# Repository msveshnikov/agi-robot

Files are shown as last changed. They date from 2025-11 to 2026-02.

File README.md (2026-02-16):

# AGI Robot

This project creates a **fully autonomous, LLM-powered mobile robot** that uses **Google Gemini 3 Flash** for real-time decision-making, navigation, and human interaction. The robot combines computer vision, distance sensing, and multi-modal AI to explore environments, accomplish goals, and engage in natural conversations.

[robot.mvpgen.com](https://robot.mvpgen.com)

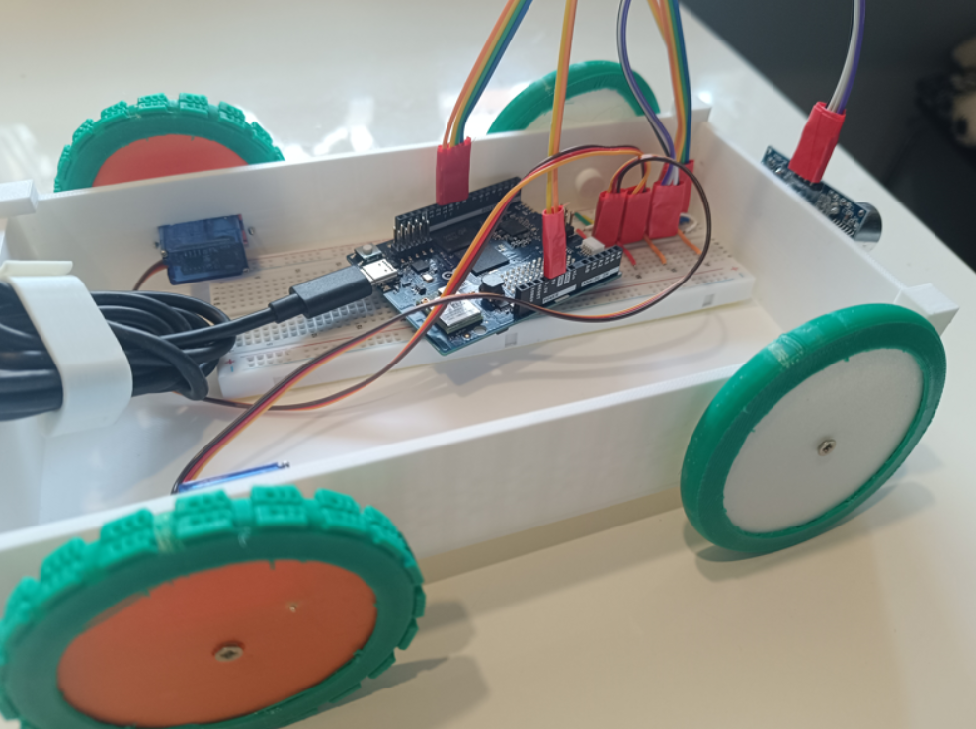
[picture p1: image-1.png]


## Key Features

- 🤖 **Autonomous Navigation**: LLM-driven pathfinding with obstacle avoidance and spatial mapping
- 👁️ **Computer Vision**: Real-time image analysis for object detection and scene understanding
- 🎤 **Voice Interaction**: Dynamically records user responses (3-15s) based on noise levels, sends audio to LLM for context-aware replies
- 🗣️ **Multi-language TTS**: Supports English, Russian, Czech, Italian, and German with Google Chirp3/Chirp-HD voices
- 🌈 **Emotional Expression**: RGB LED "mood" changes based on robot's state and manual RGB selector in dashboard
- 🏗️ **Manipulator Arm**: 2-DOF robotic arm for physical interaction with the environment (base + joint control)
- 📊 **Web Dashboard**: Modern glassmorphism interface (React/Vite) for remote monitoring, real-time telemetry, and manual override
- 📽️ **Live Camera Feed**: Real-time video streaming from robot to dashboard via Socket.IO
- 📓 **Robot Diary**: Daily "Sartre-style" blog posts automatically generated from cognitive logs
- 🧠 **Memory & Planning**: Maintains movement history, spatial maps, and hierarchical plans with file-based persistence
- � **Sound Effects**: Plays contextual sounds to attract attention or express personality
- 🚨 **Safety Features**: Panic mode for emergency navigation and Telegram alarm notifications
- 📸 **Data Logging**: Automatic image capture to Google Drive for training datasets

## Current Specifications

-   **Core Hardware:** Arduino Uno Q (Microcontroller/Motor Control)
-   **Physical Dimensions:** 24cm wide, 12cm long, **10cm high**
-   **Movement:** Two wheels with 360-degree movement capability (differential drive) - **Pins 11 (Left) & 10 (Right)**. Note: Robot can move **ONLY on the floor**.
-   **Peripherals:** USB-C dongle (USB Camera with Mic, Bluetooth Speaker)
-   **Sensors:**
    -   Proximity/Distance Sensor (Trig Pin 8, Echo Pin 9)
    -   **Modulino Thermo** (Temperature & Humidity) - Connected via I2C/Qwiic
    -   RGB LED for mood expression
-   **Power:** PowerBank 10000 mAh
-   **Software Stack:** Python 3.12+, Node.js 20+, React 18, MongoDB, Google Cloud Vertex AI (Gemini 3 Flash / Gemini 3 Pro), Pydantic (Structured Outputs)
-   **Connectivity:** WiFi required for API and Dashboard access

**Functionality:** The robot operates autonomously using an AGI loop: captures images, measures distance, consults the LLM, speaks responses, records user audio, and executes movement commands. All decisions are made by the AI model based on visual input, sensor data, goals, and conversation context.

## Project Cost

Below is a table listing all main components, their approximate cost (in USD, based on AliExpress prices), and the total amount.

| Component | Description | Cost (USD) |
| :--- | :--- | ---: |
| **Arduino Uno Q** | Main microcontroller of the project | $44 |
| **2 x SG90 9g Servos** | Motors for wheels (360°) | $4 |
| **2 x SG90 9g Servos** | Motors for manipulator arm (180°) | $4 |
| **Webcam** | Cheap Chinese USB webcam (for visual input) | $3 |
| **USB Dongle (Adapter)** | For connecting webcam and PD | $3 |
| **Ultrasonic Sensor** | For distance measurement (e.g., HC-SR04) | $1.5 |
| **Bluetooth Speaker** | For audio output or feedback | $2.5 |
| **Solderless Breadboard and Wires** | For prototyping and component connections | $5 |
| **3D Printing Plastic** | About 200 grams (for case, mounts, etc., at ~$15/kg) | $3 |
| **Xiaomi Powerbank** | 10000 mAh (for power) | $10 |
| **3D Printer** | Gift, not counted | $0 |
| **Total Project Cost** | | **$80** |

As shown in the table, the total project cost is a very affordable **$80 USD**. This clearly demonstrates that implementing interesting and functional DIY solutions doesn't always require significant investments.

**Arduino Board:** The main portion of the budget goes to the controller. Choosing more budget-friendly boards (e.g., ESP32 or ESP8266, if functionality allows) could further reduce this expense.

**Peripherals:** The webcam, dongle, sensor, and speaker are typical representatives of inexpensive yet fully functional modules widely available on the market.

**Consumables:** The cost of 3D printing plastic and basic prototyping elements (breadboard, wires) is also minimal.

### LLM API Running Cost

The robot's consciousness operates in an autonomous loop, which incurs API costs for the LLM (Gemini):
- **Loop Duration**: ~20 seconds per consciousness loop
- **Cost per Loop**: $0.005
- **Cost per Hour**: ~$1.0 (continuous operation)

---

## Design Ideas and Future Considerations

### 1. Hardware Enhancements and Modularity

| Area | Current Status | Proposed Enhancement | Rationale |
| :--- | :--- | :--- | :--- |
| **Microcontroller** | Arduino Uno Q | | |
| **Motor Control** | Integrated with Uno Q | Dedicated Motor Driver Shield (e.g., L298N or specialized drivers) | Better current handling, precision control, and separation of logic/power circuits. |
| **Sensing/Navigation** | USB Camera + Proximity + Modulino Thermo | Integrate IMU (Accelerometer/Gyroscope) | Enable robust spatial awareness, obstacle avoidance, and precise movement/pose tracking. |
| **Physical Structure** | Custom 3D Printed Chassis | | Modular housing for components, better stability, and improved aesthetics for component housing. |
| **Power Management** | Single PowerBank | | Ensure stable power for SBC, motors, and peripherals; implement low-power warning system. |

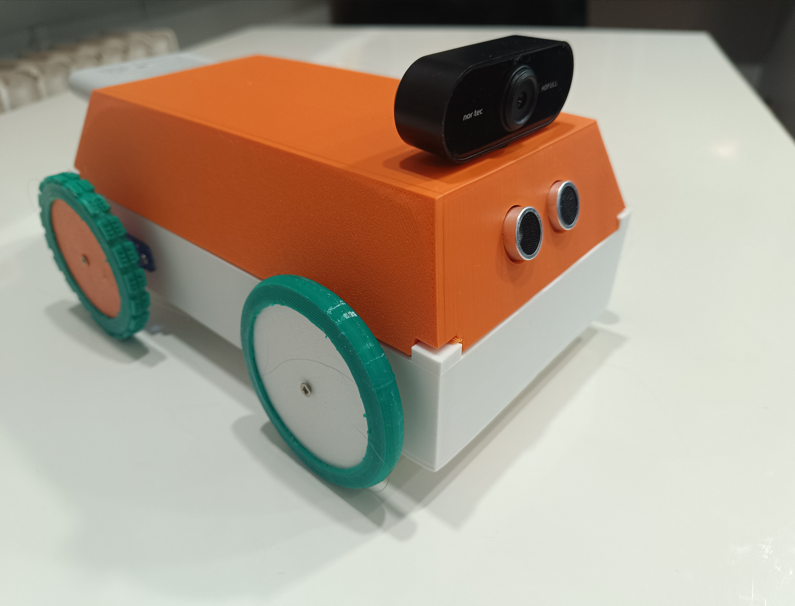
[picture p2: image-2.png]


### 2. Software Architecture and Code Structure

-   **Python Logic (`main.py`):**
    -   **AGI Loop**: Implements an autonomous loop (`agi_loop`) where the robot captures an image, checks distance, records audio responses, and consults the Gemini 3 Flash model via `media_service.py` to decide on actions.
    -   **Audio Recording**: After the robot speaks, it records user audio with **dynamic duration** (3 to 15 seconds). It monitors noise levels (dB) to extend recording if the user is speaking, and stops early on silence. During recording, the RGB LED displays a **rainbow effect**.
    -   **Object Detection**: Uses `VideoObjectDetection` to identify objects in real-time and announce them (`send_detections_to_ui`).
    -   **Backend API / Custom Backend**: Synchronizes state variables (`speed`, `agi`, `goal`, `lang`, `rgb`) and telemetry (`distance`, `temperature`, `humidity`) with our Node.js backend and web dashboard.
    -   **RGB Mood**: Converts HSV color values from backend state to RGB for the robot's "mood" LED.
    -   **Movement History**: Tracks all movement commands to prevent loops and aid navigation.
    
-   **Media Service (`media_service.py`):**
    -   **HTTP Server** (Port 5000) with the following endpoints:
        -   **GET `/play`**: Plays audio files via `aplay` (parameter: `filename`)
        -   **GET `/play_random`**: Plays a random sound from the `sounds` directory
        -   **GET `/speak`**: Text-to-Speech using Google Cloud TTS (parameters: `text`, `lang`)
            - Supports multiple languages:
              - English: `en-US-Chirp3-HD-Zubenelgenubi`
              - Russian: `ru-RU-Wavenet-D`
              - Czech: `cs-CZ-Chirp3-HD-Enceladus`
              - Italian: `it-IT-Chirp-HD-D`
              - German: `de-DE-Chirp-HD-D`
            - Implements caching to avoid re-synthesizing the same text
            - Audio output: LINEAR16 with +10dB volume gain for clarity
        -   **GET `/telegram`**: Sends alarm messages to admin via Telegram Bot (parameter: `message`)
            - Requires `TELEGRAM_KEY` and `ADMIN_ID` environment variables
        -   **POST `/llm_vision`**: Sends image, distance, plan, subplan, map, movement history, **and audio** to Gemini LLM
            - Parameters: `asi` (bool) - to select model:
                - `false` (default): **Gemini 3 Flash ** (Fast, low latency)
                - `true`: **Gemini 3 Pro** (High reasoning, slower)
            - Returns JSON with: `speak`, `sound`, `move`, `rgb`, `plan`, `subplan`, `map`, `memory`, `alarm`
            - Receives images via Socket.IO from the webcam service (default: `http://localhost:4912`)
            - **Image Logging**: Saves all incoming images to `/home/arduino/google-drive/robot` with timestamps for debugging/dataset creation
            - Includes sophisticated prompt engineering for robot behavior and safety rules
            - **Reasoning**: Uses a thinking budget (16k tokens) for complex chain-of-thought processing
            - **Alarm System**: Automatically sends Telegram notifications when LLM detects critical/dangerous conditions

-   **Arduino MCU (`sketch.ino`):**
    -   **Libraries Used**: `Arduino_RouterBridge`, `Modulino`, `Servo`, `NewPing`
    -   **Main Loop Operations**:
        1. Reads ultrasonic distance sensor (NewPing library) every 1 second
        2. Reads temperature and humidity from Modulino Thermo (I2C)
        3. Updates Cloud telemetry via Bridge notifications (`set_distance`, `set_temperature`, `set_humidity`)
    -   **Python Control Loop** (`main.py`):
        - Executes movement commands based on cloud variables (`speed`, `back`, `left`, `right`, `forward`, `panic`, `agi`)
        - Priority order: Manual controls → Panic mode → AGI mode → Stop
    -   **Manual Control**: Individual direction booleans (`back`, `left`, `right`, `forward`) with configurable speed
    -   **Panic Mode**: Emergency navigation mode - moves forward if clear (>25cm), otherwise backs up, plays random sound, and rotates
    -   **AGI Mode**: Calls `agi_loop()` function in Python, receives LLM decisions, executes complex multi-step commands
    -   **RGB Parsing**: Converts "R,G,B" string to individual values, applies hardware color correction (Red÷1.2, Green÷2, Blue×1)
    -   **Movement Calibration**:
        - Linear: ~20 cm/sec at speed 45
        - Rotation: ~40 ms/degree (empirical)
        - Safety: Stops forward movement if distance < 10cm
    -   **Bridge Functions Exposed**: `getDistance()`, `setRGB(string)`, `move(string, bool)`, `panic(int)`

# Robot Hardware Schema

## Overview

The Uno Q consists of an MCU handling motor control and an MPU (Linux Environment) handling high-level logic, vision, and audio.

## Connection Diagram

```mermaid
graph TD
    subgraph Web ["Web Infrastructure (Custom Cloud)"]
        Dashboard["React Dashboard (robot.mvpgen.com)"]
        Backend["Node.js Backend & Socket.IO"]
        DB["MongoDB (State & Logs)"]
        
        Dashboard <--> Backend
        Backend <--> DB
    end

    subgraph MPU ["MPU (Linux/Python)"]
        Python["Python Script (main.py)"]
        MediaService["Media Service (media_service.py)"]
        Webcam["USB Webcam"]
        Mic["USB Microphone"]
        Speaker["Bluetooth Speaker"]

        Python <--> MediaService
        MediaService <--> Webcam
        MediaService <--> Mic
        MediaService <--> Speaker
        MediaService <--> VertexAI["Google Vertex AI (Gemini)"]
    end

    subgraph MCU ["MCU (Arduino)"]
        Bridge["Arduino_RouterBridge"]
        ServoL["Servo Left (Pin 11)"]
        ServoR["Servo Right (Pin 10)"]
        Sensor["Proximity Sensor (Trig 8, Echo 9)"]
        Modulino["Modulino Thermo (I2C)"]
        RGB["RGB LED"]

        Bridge --> ServoL
        Bridge --> ServoR
        Bridge --> Sensor
        Bridge --> Modulino
        Bridge --> Matrix["LED Matrix (Built-in)"]
        Bridge --> RGB
    end

    Python <-->|Internal Serial| Bridge
    Python <-->|HTTP / REST| Backend
```

## Pinout Configuration

| Component | Arduino Pin | Description |
| :--- | :--- | :--- |
| **Servo Left**  | D11 | Left Wheel (Continuous Rotation)  |
| **Servo Right** | D10 | Right Wheel (Continuous Rotation) |
| **Sensor** | D8, D9 | Proximity/Distance (Trig/Echo) |
| **Modulino** | I2C | Temperature & Humidity Sensor |
| **Matrix** | Built-in | 12x8 LED Matrix |
| **RGB LED** | D4, D6, D2  | Red, Green, Blue (Common Cathode) |
| **Arm Servo 1** | D3 | Manipulator Arm Base (0-180°) |
| **Arm Servo 2** | D5 | Manipulator Arm Joint (0-180°) |
| **USB** | USB Port | Serial Communication/Webcam |

## Backend State Variables

The following variables are synchronized with the project's backend API and web dashboard (replacing Backend):

-   **Read/Write (Controls):**

    -   `agi` (bool): Master switch to enable/disable the autonomous AGI loop.
    -   `asi` (bool): Toggle to use **Gemini 3 Pro** (Smarter) instead of Flash (Faster).
    -   `goal` (str): Current main goal for the robot (retrieved from cloud).
    -   `speed` (int): Controls the speed of the robot (0-90, where 45 is baseline).
    -   `back` (bool): Command to move backward.
    -   `left` (bool): Command to turn left.
    -   `right` (bool): Command to turn right.
    -   `forward` (bool): Command to move forward.
    -   `rgb` (CloudColoredLight): RGB LED control with HSV values:
        -   `rgb:hue` (0-360): Hue value
        -   `rgb:sat` (0-100): Saturation percentage
        -   `rgb:bri` (0-100): Brightness percentage
        -   `rgb:swi` (bool): Switch on/off
        -   The Python code converts HSV to RGB string format (e.g., "255,128,0") and sends to MCU
    -   `lang` (str): Language code for TTS (en, ru, cz/cs, it, de) or "disabled" for silent mode.
    -   `panic` (bool): Emergency navigation mode toggle.
    -   `arm1` (int): Control angle for Arm Servo 1 (0-180).
    -   `arm2` (int): Control angle for Arm Servo 2 (0-180).

-   **Read-Only (Telemetry):**
    -   `distance` (int): Distance measured by the ultrasonic sensor (cm).
    -   `temperature` (float): Temperature from Modulino sensor (Celsius).
    -   `humidity` (float): Humidity from Modulino sensor (%).
    -   `plan` (str): Current global strategy/reasoning from LLM.
    -   `subplan` (str): Current tactical action description.
    -   `space_map` (str): Text-based 2D spatial map.
    -   `movement_history` (str): JSON array of past movement commands.
    -   `memory` (str): Persistent facts/knowledge learned by the robot.
    -   `alarm` (str): Current alarm status/message (empty = no alarm).

## Power Distribution

-   **Arduino**: Powered via USB PowerBank

## MPU Requirements

-   **OS**: Linux Debian 13
-   **Python**: 3.12+
-   **Ports**: 1x USB-C host for Arduino, 1x USB-A for Webcam with mic.
-   **Dependencies**: 
    -   `arduino-app-utils` (Arduino Bridge)
    -   `google-genai` (Gemini API)
    -   `google-api-python-client` (Google TTS)
    -   `python-socketio[client]` (Image streaming)
    -   `aplay` (Audio playback utility)

## Setting Up Autostart on Debian

To automatically start `media_service.py` on boot in Debian, the repository includes systemd service configuration files in the `etc/` folder.

### Installation Steps

1. **Copy the rc.local script** to `/etc/`:
   ```bash
   sudo cp etc/rc.local /etc/rc.local
   sudo chmod +x /etc/rc.local
   ```

2. **Edit `/etc/rc.local`** to update paths and credentials:
   ```bash
   sudo nano /etc/rc.local
   ```
   
   Update the following variables:
   - `GEMINI_KEY`: Your Google Gemini API key
   - Bluetooth MAC address (if using different speaker)
   - Paths to match your installation directory

3. **Copy the systemd service** file:
   ```bash
   sudo cp etc/rc-local.service /etc/systemd/system/rc-local.service
   ```

4. **Enable and start the service**:
   ```bash
   sudo systemctl daemon-reload
   sudo systemctl enable rc-local.service
   sudo systemctl start rc-local.service
   ```

5. **Check service status**:
   ```bash
   sudo systemctl status rc-local.service
   ```

### What the Script Does

The `rc.local` script performs the following on boot:
- Waits 20 seconds for system initialization
- Sets the `GEMINI_KEY` environment variable
- Connects to the Bluetooth speaker (via `bluetoothctl`)
- Creates required runtime directories for PulseAudio (`/run/user/1000/pulse`)
- Plays a startup sound to confirm audio is working
- Starts `media_service.py` from the Python directory

### Troubleshooting

- **Check logs**: `journalctl -u rc-local.service -f`
- **Manual test**: Run `/etc/rc.local start` as the arduino user
- **Bluetooth issues**: Verify speaker MAC address with `bluetoothctl devices`
- **Audio issues**: Test with `aplay -l` to confirm sound card detection

---

## Configuration

### Environment Variables

The system requires the following environment variables:

-   **`GOOGLE_APPLICATION_CREDENTIALS`**: Path to Google Cloud service account JSON file
    - Linux: `/home/arduino/google.json`
    - Windows: `C:\My-progs\Python\agi-robot\google.json`
-   **`GEMINI_KEY`**: Google Gemini API key for LLM access
-   **`IMAGE_SERVER_URL`**: Socket.IO server URL for webcam feed (default: `http://localhost:4912`)
-   **`TELEGRAM_KEY`** (optional): Telegram Bot API token for alarm notifications
-   **`ADMIN_ID`** (optional): Telegram chat ID for receiving robot alarms

### File Structure

```
agi-robot/
├── python/
│   ├── main.py              # Main robot control logic
│   ├── media_service.py     # HTTP server for TTS, LLM, and audio
│   ├── sounds/              # Directory for random sound effects (.wav files)
│   ├── memory.txt           # Persistent memory storage (auto-created)
│   └── mic.wav              # Temporary audio recording (auto-deleted after use)
├── sketch/
│   └── sketch.ino           # Arduino MCU firmware
└── google.json              # Google Cloud credentials
```

### Startup Behavior

On initialization, the robot:
1. Connects to the backend API/site and synchronizes variables
2. Initializes the webcam object detection stream
3. **RGB Rainbow**: Performs a color cycle sequence on the LED to indicate hardware readiness
4. Plays a startup sound
5. Speaks "Robot is ready" in the configured language
6. Sets default goal: **"Be helpful assistant to the master human"**
7. Begins listening for backend variable changes (AGI mode, manual controls, goal updates)

### Default Main Goal

The robot's default goal is **"Be helpful assistant to the master human"**, but this can be changed via the backend `goal` variable. When a new goal is set from the backend, the robot will speak the new goal and update its behavior accordingly.

---

## AGI Loop Behavior

The AGI Loop is the core autonomous decision-making cycle of the robot. It operates as follows:

### Input Processing

1. **Visual Input**: Captures live image from webcam via Socket.IO connection
2. **Distance Sensing**: Reads ultrasonic sensor data (0-1000 cm)
3. **Context State**: Maintains `plan`, `subplan`, `space_map`, and `movement_history`
4. **Audio Input**: After speaking, dynamically records (3-15s) to capture user responses
5. **Main Goal**: Retrieved from the backend `goal` variable

### LLM Decision-Making

The robot sends all inputs to **Gemini LLM** (Flash or Pro based on `asi` setting) with a sophisticated prompt that includes:

-   **Safety Rules**: Must stop or turn if distance < 25cm to avoid collisions (Hardware failsafe stops motors at <10cm)
-   **Navigation Strategy**: Systematic scanning by turning 30-60 degrees, approaching targets
-   **Social Behavior**: Use casual sounds to attract human attention
-   **Memory Management**: Use history to avoid loops and repeated actions
-   **Planning Hierarchy**: Global `plan` for overall strategy, `subplan` for immediate steps
-   **Spatial Mapping**: Maintain and update a text-based 2D map (1x1 meter blocks)
-   **Mood Expression**: RGB LED color reflects robot's emotional state

### LLM Response Format

The model returns a structured JSON object validated by Pydantic schemas:

```json
{
  "speak": {"text": "What I want to say"},
  "sound": "casual",
  "moves": [
    {"command": "forward|back|left|right|stop", "distance_cm": 20-300, "angle_deg": 10-180}
  ],
  "rgb": "R,G,B",
  "arm1": 0-180,
  "arm2": 0-180,
  "plan": "Global strategy description",
  "subplan": "Immediate next steps",
  "space_map": "Text-based spatial map with legend",
  "memory": "Updated persistent knowledge",
  "alarm": "Critical condition description (or empty string)"
}
```

### Action Execution

1. **Speech**: Uses Google TTS with language-specific Chirp/WaveNet voices (en/ru/cz/it/de)
2. **Audio Recording**: Captures 3-15 seconds of audio (dynamic extension) while cycling RGB colors (Rainbow) to indicate listening state.
3. **Sound Effects**: Plays random sound from `sounds/` directory to attract attention
4. **RGB Mood**: Updates LED color based on robot's emotional state:
   - White (255,255,255): Neutral/Ready
   - Green (0,255,0): Happy/Success
   - Red (255,0,0): Blocked/Frustrated
   - Blue (0,0,255): Thinking/Processing
   - Yellow (255,255,0): Curious/Searching
   - Orange (255,165,0): Cautious/Obstacle Nearby
   - Purple (128,0,128): Excited/Special Discovery
5. **Movement**: Sends command string to MCU via Bridge notification
6. **Memory**: Saves updated memory to `memory.txt` for persistence across sessions
7. **Alarm**: If alarm is non-empty, sends Telegram notification to admin
8. **Backend Sync**: Updates all state variables to the backend API and web dashboard for remote monitoring

## MCU Command Protocol

The MCU executes movement commands received from the AGI loop via the `agi_loop()` bridge function.

### Command Format

Commands are formatted as pipe-delimited strings:

**MOVE Command:**
```
MOVE|direction|distance_cm|speed
```
- `direction`: `forward` or `back`
- `distance_cm`: Distance to travel (integer)
- `speed`: Motor speed 0-90 (45 is baseline)

**TURN Command:**
```
TURN|direction|angle_deg|speed
```
- `direction`: `left` or `right`
- `angle_deg`: Rotation angle (integer)
- `speed`: Motor speed 0-90

**STOP Command:**
```
STOP
```

### Movement Calibration

The MCU uses empirical calibration values:
- **Linear Movement**: ~20 cm/sec at speed 45
- **Rotation**: ~30 ms/degree at speed 45
- Speed scaling: `actual_speed = base_speed * (requested_speed / 45.0)`

### RGB LED Processing

The MCU receives RGB values as a comma-separated string (e.g., "255,128,0") and applies color correction:
- Red: `value / 1.2`
- Green: `value / 2`
- Blue: `value` (no correction)

---

### Completed Features ✓
- [x] Multi-language TTS (English, Russian, Czech, Italian, German)
- [x] Audio recording after speech for user responses
- [x] Movement history tracking
- [x] Spatial mapping hints to LLM
- [x] RGB mood expression based on robot state
- [x] Proximity sensor integration
- [x] Google grounding for real-time web search
- [x] Persistent conversation memory across sessions (file-based)
- [x] Panic mode for emergency navigation
- [x] Telegram alarm notifications
- [x] Image logging to Google Drive
- [x] Temperature and humidity monitoring
- [x] Structured Outputs (Pydantic) for type-safe LLM responses
- [x] Manipulator arm with 2 SG90 180° servos on the roof for object interaction 
- [x] Migrate to custom backend & dashboard (React + Node.js + MongoDB)
- [x] Real-time camera feed integration in the dashboard
- [x] Settings panel in dashboard
- [x] Daily blog post (Robot Diary) from the cognitive logs
- [x] Native webcam, no bricks anymore
- [x] Broadcast robot speaking to all web clients

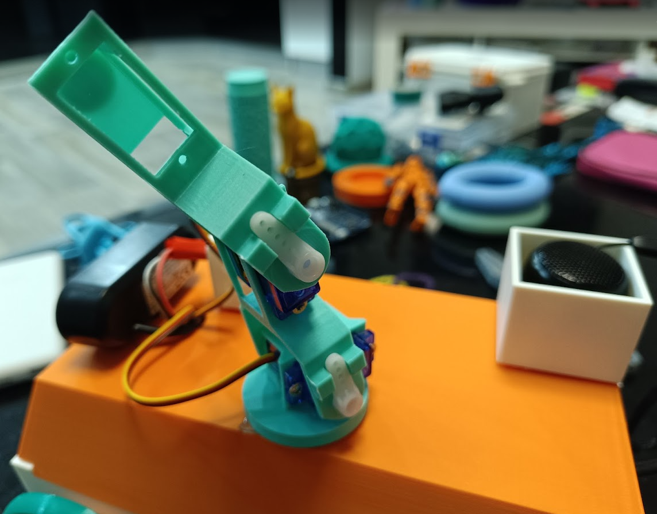
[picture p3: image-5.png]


# TODO

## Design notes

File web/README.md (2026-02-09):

# AGI Robot Web Application

Complete web interface for the AGI Robot project with React frontend, Node.js backend, and MongoDB database.

## Project Structure

```
web/
├── frontend files (React + Vite)
│   ├── src/
│   │   ├── pages/
│   │   │   ├── LandingPage.jsx
│   │   │   └── LandingPage.css
│   │   ├── App.jsx
│   │   ├── main.jsx
│   │   └── index.css
│   ├── public/
│   │   └── (robot images)
│   ├── index.html
│   ├── package.json
│   ├── Dockerfile                  # Frontend multi-stage build
│   └── nginx.conf                  # Nginx config for frontend
├── backend/
│   ├── models/
│   │   ├── RobotState.js           # Robot state schema
│   │   ├── TelemetryLog.js         # Telemetry logging
│   │   └── CommandLog.js           # Command audit trail
│   ├── routes/
│   │   └── api.js                  # REST API endpoints
│   ├── server.js                   # Express server + Socket.IO
│   ├── package.json
│   ├── Dockerfile                  # Backend Node.js image
│   ├── .env.example
│   ├── .env                        # Local development
│   ├── .env.production             # Docker production
│   └── README.md
├── docker-compose.yml              # Multi-container orchestration
└── DEPLOYMENT.md                   # Deployment guide
```

## Features

### Frontend
- 🎨 Stunning landing page with glassmorphism design
- ⚡ React 18 with Vite for fast development
- 🎭 Framer Motion animations
- 📱 Responsive design (mobile, tablet, desktop)
- 🎯 Lucide React icons

### Backend
- 🚀 Express.js REST API
- 📊 MongoDB with Mongoose ODM
- 🔄 Socket.IO for real-time updates
- 📝 Command and telemetry logging
- 🏥 Health checks

### Deployment
- 🐳 Docker Compose orchestration
- 📦 Multi-stage builds for optimization
- 🔄 GitHub Actions CI/CD
- 🌐 Automated deployment to robot.mvpgen.com

## Quick Start

### Local Development

**Prerequisites**: Node.js 18+, MongoDB (or use Docker Compose)

```bash
# Clone repository
git clone https://github.com/msveshnikov/agi-robot.git
cd agi-robot/web

# Start with Docker Compose (recommended)
docker-compose up -d

# OR run manually:

# Terminal 1 - Backend
cd backend
npm install
cp .env.example .env
npm run dev

# Terminal 2 - Frontend
cd ..
npm install
npm run dev
```

Visit:
- Frontend: http://localhost:5173
- Backend API: http://localhost:3000/api/health

### Production Deployment

See [DEPLOYMENT.md](DEPLOYMENT.md) for complete Docker Compose deployment guide.

```bash
# On VPS
cd /var/www/agi-robot
docker-compose up -d
```

## Technology Stack

**Frontend**
- React 18
- Vite
- React Router DOM
- Framer Motion
- Lucide React
- Axios
- Socket.IO Client

**Backend**
- Node.js 20
- Express.js
- MongoDB + Mongoose
- Socket.IO
- CORS
- Morgan (logging)

**DevOps**
- Docker & Docker Compose
- GitHub Actions
- Nginx (frontend server)

## Environment Variables

### Backend (.env)

```env
MONGODB_URI=mongodb://localhost:27017/agi-robot
PORT=3000
NODE_ENV=development
CORS_ORIGIN=http://localhost:5173
PYTHON_MEDIA_SERVICE_URL=http://localhost:5000
```

### Docker Production (.env.production)

```env
MONGODB_URI=mongodb://mongodb:27017/agi-robot
PORT=3000
NODE_ENV=production
CORS_ORIGIN=https://robot.mvpgen.com
PYTHON_MEDIA_SERVICE_URL=http://host.docker.internal:5000
```

## Docker Commands

```bash
# Start all services
docker-compose up -d

# View logs
docker-compose logs -f

# Restart services
docker-compose restart

# Stop services
docker-compose down

# Rebuild
docker-compose build --no-cache

# Check status
docker-compose ps
```

## Development

### Frontend Development

```bash
cd web
npm install
npm run dev        # Development server
npm run build      # Production build
npm run preview    # Preview production build
```

### Backend Development

```bash
cd web/backend
npm install
npm run dev        # Development with auto-reload
npm start          # Production mode
```

## API Documentation

See [backend/README.md](backend/README.md) for complete API documentation.

### Key Endpoints

- `GET /api/state` - Current robot state
- `POST /api/state` - Update robot state
- `POST /api/control/move` - Movement commands
- `POST /api/control/agi` - Toggle AGI mode
- `POST /api/control/panic` - Emergency mode
- `GET /api/telemetry` - Historical sensor data
- `GET /api/logs/commands` - Command history

### Real-time Events (Socket.IO)

- `state` - Robot state changes
- `telemetry` - Live sensor updates
- `camera` - Camera feed

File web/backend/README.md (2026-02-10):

# AGI Robot Backend

Backend API server for AGI Robot control and telemetry.

## Features

- RESTful API for robot control
- Real-time telemetry via Socket.IO
- MongoDB for state and logging
- Command audit trail
- CORS-enabled for frontend integration

## Models

Detailed documentation of the data models can be found in [MODELS.md](./MODELS.md).

## Prerequisites

- Node.js 18+
- MongoDB 5.0+

## Installation

```bash
cd web/backend
npm install
```

## Configuration

Copy `.env.example` to `.env` and update values:

```bash
cp .env.example .env
```

Required environment variables:
- `MONGODB_URI`: MongoDB connection string
- `PORT`: API server port (default: 3000)
- `CORS_ORIGIN`: Frontend URL for CORS
- `PYTHON_MEDIA_SERVICE_URL`: Media service endpoint

## Development

```bash
npm run dev
```

## Production

```bash
npm start
```

Or use PM2:
```bash
pm2 start server.js --name agi-robot-backend
```

## API Endpoints

### State Management
- `GET /api/state` - Get current robot state
- `POST /api/state` - Update robot state

### Control
- `POST /api/control/move` - Send movement command
- `POST /api/control/agi` - Toggle AGI mode
- `POST /api/control/panic` - Toggle panic mode
- `POST /api/control/rgb` - Update RGB LED
- `POST /api/control/arm` - Update arm positions

### Data Retrieval
- `GET /api/telemetry` - Get telemetry history
- `GET /api/logs/commands` - Get command history

### Other
- `GET /api/health` - Health check
- `POST /api/speak` - Text-to-speech

## Socket.IO Events

### Emitted by Server
- `state` - Robot state updates
- `telemetry` - Real-time telemetry data
- `camera` - Camera feed (broadcast)

### Received by Server
- `camera` - Camera feed from client

## Deployment

Automated via GitHub Actions to robot.mvpgen.com. See `.github/workflows/deploy.yml`.

## License

MIT

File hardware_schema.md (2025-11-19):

# Robot Hardware Schema

## Overview
The robot consists of an MCU (Arduino) handling motor control and an MPU (PC/SBC) handling high-level logic, vision, and audio. They are connected via USB (Serial).

## Connection Diagram

```mermaid
graph TD
    subgraph MPU ["MPU (Computer/SBC)"]
        Python[Python Script]
        Webcam[USB Webcam]
        Mic[USB Microphone]
        Speaker[USB Speaker]
        
        Python <--> Webcam
        Python <--> Mic
        Python <--> Speaker
    end

    subgraph MCU ["MCU (Arduino)"]
        Bridge[Arduino_RouterBridge]
        Servo1[Servo 1 (Head)]
        Servo2[Servo 2 (Left Arm)]
        Servo3[Servo 3 (Right Arm)]
        Servo4[Servo 4 (Base/Other)]
        
        Bridge --> Servo1
        Bridge --> Servo2
        Bridge --> Servo3
        Bridge --> Servo4
    end

    Python <==>|USB Serial (115200 baud)| Bridge
```

## Pinout Configuration

| Component | Arduino Pin | Description |
| :--- | :--- | :--- |
| **Servo 1** | D3 | Head Rotation (0-180°) |
| **Servo 2** | D5 | Left Arm (0-180°) |
| **Servo 3** | D6 | Right Arm (0-180°) |
| **Servo 4** | D9 | Base/Aux (0-180°) |
| **USB** | USB Port | Serial Communication with MPU |

## Power Distribution
- **Arduino**: Powered via USB or external 7-12V DC jack.
- **Servos**: **CRITICAL**: Do NOT power 4 servos directly from the Arduino 5V pin. Use an external 5V power supply (e.g., 4xAA battery pack or 5V/2A adapter) for the servos. Connect the external power ground to Arduino GND.

## MPU Requirements
- **OS**: Linux Debian
- **Python**: 3.12+
- **Ports**: 1x USB for Arduino, 1x USB for Webcam, 1x USB for Audio (or 3.5mm jacks).

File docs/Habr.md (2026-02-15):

# Как я собрал робота с характером на базе Gemini API и Arduino Uno Q (и научил его подмигивать)

Привет, Хабр!

Вы когда-нибудь мечтали о роботе, который не просто выполняет команды «едь прямо» или «поверни налево», а может обидеться на вас за глупый вопрос или радостно подмигнуть, увидев кота? Я тоже. И решил, что хватит мечтать — пора собирать.

В этой статье я расскажу, как за пару вечеров собрал "гипер-интерактивного" робота, используя **Arduino Uno Q**, немного Python-магии и **Google Gemini Robotics API**. У него нет рук, нет ног, но есть колеса, матричное лицо и, самое главное, — характер.

<cut/>

## Идея: "Мозг" и "Мышцы"

Главная проблема DIY-роботов — вычислительная мощность. Обычно приходится выбирать между Arduino (хорошо крутит моторами) и Raspberry Pi (умеет думать). Но **Arduino Uno Q** меняет правила игры. Она объединяет в себе и то, и другое:

1.  **MPU (Main Processing Unit)**: Мощный "мозг" на Python, который видит, слышит и общается с LLM (Large Language Model).
2.  **MCU (Microcontroller Unit)**: "Мышцы" (C++), которые дергают сервоприводами, светят светодиодами и следят за датчиками.

## Железо: Из чего же сделаны наши мальчишки?

Сборка получилась максимально доступной, но с парой интересных апгрейдов:

-   **Arduino Uno Q**: Звезда шоу. Встроенная LED-матрица 12x8 — это киллер-фича для создания "лица" робота.
-   **Modulino Thermo**: Сенсор температуры и влажности (потому что робот должен знать, когда ему жарко).
-   **Шасси**: Классическая двухколесная платформа (differential drive).
-   **Сервоприводы**: 2 штуки постоянного вращения (Continuous Rotation) для колес.
-   **Сенсоры**: Ультразвуковой датчик расстояния (NewPing) — глаза робота "на ощупь".
-   **Периферия**: USB-вебкамера, микрофон и динамик (подключены к USB MPU).

Схема подключения теперь включает Modulino:

```mermaid
graph TD
    subgraph Arduino Uno Q
        MPU[Python MPU] <-->|Internal Serial| MCU[Arduino MCU]
    end
    MCU --> LeftMotor[Левый мотор]
    MCU --> RightMotor[Правый мотор]
    MCU --> Modulino[Modulino Temp/Hum]
    MCU --> Sonar[УЗ Датчик]
    MCU --> Matrix[Матрица 12x8]
```

## 3D-печать: Сам себе инженер

Вся механика робота распечатана на 3D-принтере. Я использовал OpenSCAD для создания параметрических моделей — это позволяет легко менять размеры колес или шасси, просто поменяв пару переменных в коде. Модели (`.scad` и `.stl`) лежат в папке `3d`.

## Софт: Эволюция до AGI

Самое вкусное — это софт. Архитектура проекта немного усложнилась и разделилась на сервисы для большей гибкости.

### 1. Arduino (C++) — "Мышцы и Рефлексы"

Микроконтроллер теперь не просто "дёргает ногами", а слушает команды высокого уровня через `agi_loop`.

Основные функции скетча:
-   **Сбор телеметрии**: Читает дистанцию с сонара, температуру/влажность с Modulino и отправляет это в Backend/MPU.
-   **Исполнительный механизм**: Парсит строковые команды вида `MOVE|forward|20|45` (ехать вперед 20см со скоростью 45) или `TURN|left|60|45` (поворот на 60 градусов).
-   **Safety**: Если датчик расстояния видит препятствие в упор, робот меняет дистанцию на "бесконечность" (чтобы не паниковать) или останавливается — простейший рефлекс.

### 2. Python (MPU) — "Дирижер" (`main.py`)

Этот скрипт связывает облако Arduino, низкоуровневые команды и "высший разум".
Он запускает непрерывный цикл (на стороне Arduino вызывается как `agi_loop`), который:
1.  Получает текущую дистанцию.
2.  Отправляет запрос в **Media Service**.
3.  Получает JSON с планом действий.
4.  Транслирует план в простые команды для Arduino (`MOVE`, `TURN`).

### 3. Media Service & LLM — "Высший Разум" (`media_service.py`)

Вся "тяжелая" логика вынесена в отдельный HTTP микросервис. Это позволяет не блокировать основной поток управления.
Здесь живет `Gemini Robotics ER 1.5 Preview`.

**System Prompt** стал намного серьезнее. Теперь мы учим робота не только болтать, но и планировать (Reasoning):

```python
schema_instructions = (
    "You are a smart robot assistant with two wheels and NO arms or head. "
    "Your inputs are: 1. Current image from webcam. 2. Ultrasonic distance reading. 3. Your goal. 4. Movement history. "
    "BEHAVIOR RULES:\n"
    "1. SAFETY FIRST: If 'distance' < 25 cm, you ARE BLOCKED. Mod Back or Turn.\n"
    "2. MEMORY: Use 'movement_history' and 'subplan' to avoid loops.\n"
    "3. REASONING: Explain strategy in 'subplan'."
)
```

**JSON Schema** ответа теперь включает "внутренний монолог" (`subplan`) для памяти:

```json
{
    "speak": { "text": "Вижу елку, двигаюсь к ней." },
    "move": { 
        "command": "forward", 
        "distance_cm": 50, 
        "angle_deg": 0 
    },
    "subplan": "Target visible at center. Closing distance. Scanned left side previously."
}
```

## Как это работает в жизни

1.  **Vision Loop**: Кадр с веб-камеры улетает в модель вместе с историей последних движений.
2.  **Reasoning**: Gemini анализирует картинку: "Ага, передо мной стена, а цель (Найти елку) еще не выполнена. Слева свободно".
3.  **Action**: Генерирует JSON: `move: { command: "left", angle_deg: 45 }`, `subplan: "Turning left to avoid wall and scan new area"`.
4.  **Execution**: `main.py` превращает это в `TURN|left|45|45` и шлет в Arduino.
5.  **Feedback**: Arduino поворачивает сервы, и цикл повторяется.

Такой подход с `subplan` и `movement_history` позволяет роботу не застревать в углах и вести себя более осмысленно, чем простой реактивный бот.

### Пример диалога (логи):

```text
DEBUG: robot.main: AGI loop called with distance: 154, current subplan: Scanning room...
INFO: SoundService: Sending text+image to Gemini Robotics model...
INFO: robot.main: Speak service called: Speaking: Вижу что-то зеленое.
INFO: robot.main: AGI cmd: MOVE|forward|30|45
```

## Грабли, на которые я наступил

1.  **Питание сервоприводов**: Никогда, слышите, НИКОГДА не питайте моторы от 5V пина Arduino. Я поплатился часами отладки "почему оно перезагружается при повороте". Только внешнее питание!
2.  **JSON Hallucinations**: Иногда LLM забывает закрыть скобку или добавляет лишний текст. Пришлось добавить `try-except` и очистку от markdown-тегов.
3.  **Задержки**: Обработка картинки и запрос к API занимают время (1-2 секунды). Для real-time гонок не пойдет, но для вдумчивого собеседника — вполне.

## Итоги

Проект получился живым. Это не просто машинка на радиоуправлении, это сущность, которая _понимает_, что происходит вокруг. Добавление эмоций через LED-матрицу и глаза кардинально меняет восприятие устройства. Оно кажется... живым?

**Что дальше?**

-   Добавление манипулятора (руки!), чтобы он мог не только смотреть, но и трогать.
-   SLAM навигация.

Код проекта открыт и доступен на GitHub: [https://github.com/msveshnikov/agi-robot](https://github.com/msveshnikov/agi-robot)

Так что дерзайте! Роботы — это весело. Особенно когда они умеют злиться.

---

_P.S. Если робот начнет просить коды запуска ядерных ракет, я его отключу. Обещаю._

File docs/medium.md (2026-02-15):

# Building a "Sentient" Robot with Gemini AI and Arduino Uno Q: From Plastic Parts to Digital Personality

Have you ever looked at a standard Roomba or a basic RC car and felt... nothing? Most robots we interact with are purely reactive—slaves to their sensors and hardcoded logic. They don't have "off days," they don't get curious, and they certainly don't have a personality.

I decided to change that. I wanted to build a robot that doesn't just execute "move forward" commands but one that can actually get offended by a silly question, wink joyfully when it sees a cat, or "pout" in a corner when it fails a task or runs into a wall. This isn't just about automation; it's about *embodiment*.

In this article, I’ll take you through the deep technical journey of creating a "hyper-interactive" robot using the **Arduino Uno Q**, a heavy dose of Python-mediated services, and the **Google Gemini API**. It has no arms (yet) or legs, but it has wheels, a matrix face, and most importantly—a digital soul.

---

## The Philosophy: Why "Embodied" AI Matters

We often think of Large Language Models (LLMs) as brains in a jar—powerful, but disconnected from the physical world. By putting Gemini into a mobile chassis, we move from "Chatbot" to "Embodied Agent." Suddenly, the AI has to deal with real-world physics: battery life, slippery floors, and the fact that a "wall" isn't just a word, but a physical barrier it needs to avoid.

### The Brains and the Brawn: Dividing the Labor
The main challenge with DIY robotics is computational power. You usually have to choose between an Arduino (great at precise motor control and low-latency response) and a Raspberry Pi (great at heavy lifting and networking). The **Arduino Uno Q** is a revolutionary middle ground. It lives in two worlds:

1.  **MPU (Main Processing Unit)**: A Linux-based "brain" that runs Python. It handles the USB camera, microphone, and talks to the heavy-duty Gemini APIs via HTTP and WebSockets.
2.  **MCU (Microcontroller Unit)**: A classic ATMega-style "muscle" (C++) that manages the high-frequency PWM (Pulse Width Modulation) for the servos, reads the ultrasonic sensor's trigger/echo pins, and updates the LED matrix at 60Hz.

By splitting the logic, we ensure that while the "Brain" is pondering the meaning of a cat video, the "Muscle" is still actively checking if the robot is about to drive off a cliff.

---

## Hardware Architecture: What’s Under the Hood?

The build is designed to be accessible but punchy, using a mix of off-the-shelf modules and custom 3D-printed parts.

*   **Arduino Uno Q**: The centerpiece. Its built-in 12x8 LED matrix is the "face" of our robot. We treat this matrix as a low-resolution canvas for eyes, blinking patterns, and "angry" eyebrows.
*   **Modulino Thermo**: To give the robot a sense of its environment. If the temperature spikes, Gemini might decide the robot is "sweating" and look for a cooler spot in the room.
*   **Ultrasonic Ranger (HC-SR04)**: The "on-the-ground" eyes. While the camera sees the world at 30fps, the ultrasound can trigger an emergency stop in milliseconds if an obstacle appears suddenly.
*   **Continuous Rotation Servos**: Unlike standard servos that move to a specific angle, these act as DC motors with built-in speed controllers, allowing for smooth, differential-drive movement.
*   **Peripherals**: A standard 720p USB webcam, a USB microphone, and a small dedicated speaker (connected via a USB-to-3.5mm adapter) for that WaveNet voice output.

---

## OpenSCAD: Engineering as Code

One of the most satisfying parts of this project was designing the physical body. I didn't use Illustrator or traditional CAD tools. Instead, I used **OpenSCAD**. 

In OpenSCAD, you don't "draw" a wheel; you write a function to generate it. This "Code-as-CAD" approach is a game-changer for iterative robotics. It allows for **Parametric Design**.

### The Power of Parametric Iteration
I created models where every dimension is a variable. Need to switch to larger wheels because the robot is slipping on the rug? I just change one line: `wheel_diameter = 80;`. The code instantly recalculates the tread pattern density, the mounting hole positions relative to the servo horn, and the clearance for the chassis.

For example, here is how the custom tread pattern on the wheel is generated using a simple loop:

```openscad
// Parametric wheel tread generation
module tread_cutter() {
    if (tread_grooves > 0) {
        for (i = [0 : 360/tread_grooves : 359]) {
            rotate([0, 0, i]) {
                // translate the cutting box to the rim
                translate([wheel_diameter/2 - tread_groove_depth, -tread_groove_width/2, -1]) {
                    cube([tread_groove_depth + 1, tread_groove_width, wheel_thickness + 2]);
                }
            }
        }
    }
}
```

This scriptable approach allowed me to Git-control my hardware. Every change to the 3D model is a commit, just like my Python code. The chassis, the camera mount, and even the speaker dock were all "programmed" this way, ensuring that if I break the mounting bracket, I can just re-render and re-print a perfect copy.

---

## Software Infrastructure: A Symphony of Three Layers

To keep the robot responsive and "smart" at the same time, I designed a tri-layer architecture:

### 1. The Reactive Layer (Arduino MCU - C++)
This is the robot's spinal cord. It operates on a tight `loop()`. It's responsible for:
*   **Telemetry Aggregation**: Polling the Modulino sensors and the Ultrasound.
*   **Servo Control**: Writing pulse widths to the pins to maintain constant speed.
*   **Safety Interlocks**: A hardware-to-hardware reflex. If the distance drops below 15cm, the MCU kills the motor power immediately, regardless of what the Python script is requesting.

### 2. The Coordination Layer (Python MPU - main.py)
This is the robot's autonomic nervous system. It handles:
*   **Bridging**: Communicating with the Backend IoT variables.
*   **Media Pipeline**: Capturing MJPEG frames from the `/dev/video0` device and managing the audio recording thread.
*   **State Management**: It keeps track of the "Local Plan" so that if the internet drops for a second, the robot doesn't just freeze mid-turn.

### 3. The Cognitive Layer (Media Service - Python/FastAPI)
This is the "Prefrontal Cortex" residing in a separate HTTP microservice. This is where **Gemini 1.5 Pro/Flash** lives. By decoupling this, I can switch between different LLMs or update the robot's "personality" (by changing the system prompt) without ever having to re-flash the Arduino or restart the robot's main loop.

---

## Multimodal Intelligence: Living in a Human World

The robot doesn't just "see" pixels; it perceives a situation. We send a rich, multimodal context to Gemini that includes:
*   **The Vision**: A high-compression JPEG from the webcam.
*   **The Memory**: The last 15 entries in the `movement_history` log (to prevent the robot from going back and forth like a trapped glitch).
*   **The Vitals**: Temperature, humidity, and the obstacle distance in centimeters.
*   **The User Context**: What I just said to it, and its current high-level goal.

### Two-Way Audio: The Listening Loop
One of the major breakthroughs in the project was the "Listening Window." Conversations with robots often feel robotic because they don't know when to listen. My implementation works like this:
1.  **Speak**: The robot synthesizes a response using Google's **WaveNet TTS** (which sounds incredibly human).
2.  **Listen**: As soon as the audio playback finishes, a recording thread triggers for 10 seconds.
3.  **Process**: The system uses the Python `wave` module to ensure bit-perfect headers (44.1kHz, 16-bit mono).
4.  **Send**: This audio chunk is encoded to Base64 and shipped to Gemini as part of the *next* request. This allows Gemini to "hear" my tone—if I sound frustrated, the robot can apologize.

### Emotional Feedback through Color
To give the robot a "mood," I added a high-intensity RGB LED driven by the MCU via PWM. Gemini itself decides the robot's color based on its internal state:
*   🟢 **Green (Joy)**: Goal achieved. For example, "I see the Christmas tree!"
*   🔴 **Red (Anger/Panic)**: "I'm blocked and I don't know why."
*   🔵 **Blue (Thinking)**: Used when the robot is waiting for an API response.
*   🟡 **Yellow (Investigation)**: "I see something unfamiliar; moving closer to inspect."

---

## Poor Man's SLAM: The Text-Mode Mapper

True SLAM (Simultaneous Localization and Mapping) is a computationally expensive beast that usually requires a $500 LIDAR and a lot of Linear Algebra. I wanted to see if I could use **LLM Reasoning** as a substitute for a LIDAR.

I instructed Gemini to maintain an internal "ASCII Reality" in its memory string. It builds and updates a 2D grid representation of its environment:

```text
Visualized Space Map:
[W] [W] [D] [W] [W]
[W] [.] [.] [.] [W]
[W] [.] [R] [S] [W]
[W] [P] [P] [.] [W]
[W] [W] [W] [W] [W]

Legend: W=Wall, D=Door, S=Sofa, R=Robot, P=Previous Path, .=Clearance
```

On every cycle, Gemini updates the position of 'R' and labels discovered objects. Because this string is passed back into the "System Context" for the next turn, the robot has **Spatial Persistence**. It knows that the sofa is behind it, even if its camera is currently pointed at a blank wall.

---

## The Technical "Gotchas": Lessons from the Trenches

Building this was a series of hard-won lessons in electrical engineering and prompt engineering:

1.  **The "Motor Twitch" & Power Sags:** Initially, the robot would randomly reboot whenever it tried to accelerate. The issue? High-torque servos pull significant current spikes. When they started, the voltage on the rail would drop just enough to brown out the Arduino's MPU. **The Fix:** I moved the servos to a dedicated 2A buck converter, keeping the logic and motors electrically isolated.
2.  **JSON Hallucinations:** Even the best LLMs sometimes add extra chatter. Gemini might respond with: *"Sure! Here is your command: { ... }"*. This extra text breaks `json.loads()`. I had to write a **Robust JSON Extractor** using regex that searches for the first `{` and the last `}` to strip away any conversational "fluff."
3.  **Audio Latency Optimization:** Waiting for a full TTS synthesis and then playing it can take 4-5 seconds. To make the robot feel "snappier," I implemented a **Local TTS Cache**. If the AI decides to say something common (like "Looking around..."), the Python script plays the cached version instantly while it continues to process the more complex parts of the plan in the background.

---

## Conclusion: The Future of Our Tiny Friend

The robot has evolved from a simple Python script to a genuinely interesting companion. It has its favorite spots in the room, it "gets annoyed" by low-light conditions, and it seems to have a real sense of purpose when "hunting" for an object.

What's next for the AGI-Robot?
*   **Vectorized Memory (RAG):** Using a local vector database so the robot can remember things I told it weeks ago.
*   **Physical Manipulation:** Designing a 3D-printed 3-DOF arm to allow it to move small objects.
*   **Collaborative Robotics:** Connecting multiple robots to the same "Hive Mind" so they can map a room together.

The entire project—from the OpenSCAD files to the media services—is open-source. If you've ever wanted to build something that lives at the intersection of hardware and human-level AI, there's never been a better time.

**[Explore the Source Code on GitHub](https://github.com/msveshnikov/agi-robot)**

---

**Hardware Checkpoint**:
*   *Chassis Status*: Printed and Assembled
*   *Vision*: Online
*   *Logic*: Gemini 1.5 Enabled
*   *Mood*: Currently Curious 🟡

*P.S. If the robot starts asking for the Wi-Fi password to the local power grid, I’m pulling the plug. Until then, we’re good.*

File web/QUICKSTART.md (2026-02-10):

# AGI Robot Web Application - Quick Start Guide

## Local Development

### Prerequisites
- Node.js 18+
- MongoDB running (or use Docker Compose)

### Option 1: Docker Compose (Recommended)

Start all services with one command:

```bash
cd web
docker-compose up -d
```

This starts:
- MongoDB on port 27017 (internal)
- Backend API on port 3000
- Frontend on port 80

Access:
- Frontend: http://localhost
- Dashboard: http://localhost/dashboard  
- API: http://localhost:3000/api/health

### Option 2: Manual Development Mode

**Terminal 1 - Backend**:
```bash
cd web/backend
npm install
cp .env.example .env
npm run dev
```

**Terminal 2 - Frontend**:
```bash
cd web
npm install
npm run dev
```

Access:
- Frontend: http://localhost:5173
- Dashboard: http://localhost:5173/dashboard
- API: http://localhost:3000/api/health

## Features

### Landing Page (/)
- Stunning glassmorphism design
- Project features showcase
- Technical specifications
- Cost breakdown table
- Call-to-action to dashboard

### Dashboard (/dashboard)
- **Live Telemetry**: Distance, temperature, humidity
- **Movement Controls**: Forward, back, left, right, stop
- **Robot Modes**: AGI, Panic, ASI toggles
- **Real-time Updates**: Socket.IO connection

## API Endpoints

### Control
- `POST /api/control/move` - Move robot
- `POST /api/control/agi` - Toggle AGI mode
- `POST /api/control/panic` - Toggle panic mode
- `POST /api/control/rgb` - Set LED color
- `POST /api/control/arm` - Set arm positions

### Data
- `GET /api/state` - Current robot state
- `POST /api/state` - Update state
- `GET /api/telemetry` - Historical telemetry
- `GET /api/logs/commands` - Command history

## Deployment

### GitHub Actions
Push to `main` branch:
```bash
git add .
git commit -m "Deploy updates"
git push origin main
```

Automatically deploys to robot.mvpgen.com via Docker Compose.

### Manual VPS Deployment

On VPS:
```bash
cd /var/www/agi-robot
docker-compose pull
docker-compose build
docker-compose up -d
```

See [DEPLOYMENT.md](DEPLOYMENT.md) for complete setup guide.

## Testing the Dashboard

1. **Start Backend**: Ensure MongoDB and backend are running
2. **Start Frontend**: Access http://localhost:5173/dashboard
3. **Check Connection**: Green indicator = Socket.IO connected
4. **Try Controls**: 
   - Click movement buttons (Forward, Back, Left, Right)
   - Toggle AGI or Panic modes
   - Watch telemetry update in real-time

## Troubleshooting

### "Cannot connect to backend"
- Check backend is running: `npm run dev` in `web/backend/`
- Verify MongoDB is running: `docker ps` or `systemctl status mongod`
- Check API URL in `.env`: `VITE_API_URL=http://localhost:3000`

### "Socket.IO disconnected"
- Backend must be running for WebSocket connection
- Check browser console for errors
- Verify CORS settings in backend `.env`

### Frontend won't start
- Delete `node_modules` and reinstall: `rm -rf node_modules && npm install`
- Clear Vite cache: `rm -rf .vite`

## Project Structure

```
web/
├── src/
│   ├── pages/
│   │   ├── LandingPage.jsx        # Home page
│   │   ├── Dashboard.jsx          # Control dashboard
│   │   └── *.css
│   ├── components/
│   │   ├── TelemetryCard.jsx      # Telemetry display
│   │   ├── ControlButton.jsx      # Interactive buttons
│   │   └── *.css
│   ├── services/
│   │   ├── api.js                 # Backend API calls
│   │   └── socket.js              # Socket.IO service
│   ├── App.jsx                    # Router configuration
│   └── index.css                  # Design system
├── backend/
│   ├── models/                    # MongoDB schemas
│   ├── routes/                    # API routes
│   ├── server.js                  # Express + Socket.IO
│   └── package.json
├── docker-compose.yml             # Multi-container setup
└── package.json
```

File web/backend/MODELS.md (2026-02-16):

# Backend Data Models

This document outlines the Mongoose models used in the AGI Robot backend.

## 1. BlogPost

Represents a generated blog post, typically creating a narrative from the robot's logs.

- **File**: `models/BlogPost.js`
- **Schema**:
  - `title` (String, required): The title of the blog post.
  - `content` (String, required): The main body text of the post.
  - `date` (Date, default: `Date.now`): When the post was created. Indexed for sorting.
  - `logsCount` (Number, required): Number of logs aggregated to create this post.

## 2. CognitiveLog

Stores the robot's internal cognitive state, including plans and goals.

- **File**: `models/CognitiveLog.js`
- **Schema**:
  - `plan` (String): The high-level plan the robot is executing.
  - `subplan` (String): Specific steps or immediate sub-goals.
  - `memory` (String): Short-term or context-specific memory string.
  - `goal` (String): The current overarching goal.
  - `timestamp` (Date, default: `Date.now`): Time of the log entry. Indexed.

## 3. CommandLog

Records commands sent to or executed by the robot.

- **File**: `models/CommandLog.js`
- **Schema**:
  - `timestamp` (Date, default: `Date.now`): Time of the command. Indexed.
  - `command_type` (String, required): Type of command. 
    - Enum: `['move', 'turn', 'stop', 'agi', 'panic', 'speak', 'rgb', 'arm']`
  - `command_data` (Mixed): Additional parameters for the command (e.g., speed, angle).
  - `llm_response` (Mixed): The raw response from the LLM if the command originated there.
  - `source` (String, default: 'user'): Origin of the command.
    - Enum: `['user', 'agi', 'panic', 'api']`

## 4. RobotState

The single source of truth for the robot's current capabilities and status. Note that this collection likely contains a single document representing the "current" state.

- **File**: `models/RobotState.js`
- **Schema**:
  - **Control Variables**:
    - `agi` (Boolean): AGI mode active.
    - `asi` (Boolean): ASI mode active.
    - `speed` (Number): Movement speed (0-90).
    - `panic` (Boolean): Emergency stop state.
    - `forward`, `back`, `left`, `right` (Boolean): Directional flags.
    - `lang` (String): Language setting (default 'en').
    - `goal` (String): Current mission statement.
  - **RGB Control** (HSV format):
    - `rgb.hue` (0-360)
    - `rgb.sat` (0-100)
    - `rgb.bri` (0-100)
    - `rgb.swi` (Boolean): Switch state.
  - **Arm Control**:
    - `arm1` (Number): Position of arm joint 1 (0-180).
    - `arm2` (Number): Position of arm joint 2 (0-180).
  - **Telemetry** (Read-only):
    - `distance` (Number): Ultrasonic sensor reading.
    - `temperature` (Number)
    - `humidity` (Number)
  - **Planning & Memory**:
    - `plan`, `subplan`, `space_map`, `memory`.
    - `movement_history` (Array of Strings).
  - **Alarm**:
    - `alarm` (String)

## 5. TelemetryLog

Historical record of sensor data.

- **File**: `models/TelemetryLog.js`
- **Schema**:
  - `timestamp` (Date, default: `Date.now`): Indexed.
  - `distance` (Number, required): Distance sensor reading.
  - `temperature` (Number)
  - `humidity` (Number)

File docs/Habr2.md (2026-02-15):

# Мой робот научился слушать, злиться и даже краснеть (как я прокачал AGI-робота до уровня "почти человек")

Привет снова, Хабр!

Помните моего робота на Arduino Uno Q с характером? Того, который умел подмигивать и обижаться? Так вот, за пару месяцев он **серьезно прокачался**. Теперь он не просто ездит и болтает, а:

- 🎤 **Слушает ответы** после того, как сам поговорил (и отправляет их в LLM для контекста!)
- 🌈 **Светится разными цветами** в зависимости от настроения (красный = злой, зеленый = радостный, синий = думает)
- 🗣️ **Говорит на трех языках** (английский, русский, чешский) голосами WaveNet от Google
- 🗺️ **Рисует карту комнаты** прямо в текстовом режиме
- 🧠 **Помнит свои движения**, чтобы не застревать в углах как пылесос из 2005-го

В этой статье я расскажу, **как превратить простого робота в почти разумное существо**, используя мультимодальный Gemini API, и почему мой робот теперь умнее некоторых людей (шутка... или нет?).

<cut/>

## Что изменилось с прошлой версии?

В первой статье я описывал базовый AGI-цикл: камера → LLM → команда → движение. Это работало, но роботу **не хватало контекста**. Он не помнил, куда ехал, не понимал мои ответы и вообще вел себя как безэмоциональный тостер на колесах.

Вот что я добавил:

### 1. 🎤 Аудио-взаимодействие (наконец-то двусторонняя связь!)

Раньше робот говорил, но не **слушал**. Это как разговаривать с начальником — односторонний разговор. Теперь после каждого своего высказывания робот включает микрофон на **10 секунд** и записывает ответ пользователя в WAV-файл с правильными заголовками.

```python
# Из main.py - после того как робот что-то сказал
mic = Microphone()
mic.start()
with wave.open("mic.wav", "wb") as wf:
    wf.setnchannels(1)
    wf.setsampwidth(2)  # S16_LE
    wf.setframerate(16000)
    
    for chunk in mic.stream():
        wf.writeframes(chunk.tobytes())
        if time.time() - start_time >= 10:
            break
```

Потом этот файл **base64-кодируется** и отправляется в Gemini вместе с картинкой и всеми остальными данными:

```python
# media_service.py - мультимодальный запрос
contents = [
    types.Content(
        role="user",
        parts=[
            types.Part.from_text(text=prompt_text),
            types.Part.from_bytes(data=image_bytes, mime_type="image/jpeg"),
            types.Part.from_bytes(data=audio_bytes, mime_type="audio/wav")  # ВОТ ОНО!
        ]
    )
]
```

Теперь я могу **сказать роботу**, куда ехать, и он меня услышит. Буквально. Это как Siri, только на колесах и с камерой.

### 2. 🌈 RGB LED "настроение" (эмоции через цвет)

Раньше у робота была только LED-матрица для "лица". Теперь на крыше стоит трехцветный RGB-светодиод (пины D3, D5, D6), который **показывает эмоции**:

| Цвет | Настроение | Когда горит |
|---|---|---|
| 🟢 Зеленый | Радость/Успех | Нашел цель, выполнил задачу |
| 🔴 Красный | Злость/Блокировка | Застрял, препятствие < 25см |
| 🔵 Синий | Думает/Планирует | Обрабатывает данные, размышляет |
| 🟡 Желтый | Любопытство | Исследует новую зону |
| 🟠 Оранжевый | Осторожность | Рядом препятствие, но еще не критично |
| ⚪ Белый | Нейтральный | Дефолтное состояние |

LLM **сам решает**, какой цвет выбрать, основываясь на ситуации. В промпте прописаны четкие правила:

```python
# Из media_service.py
\"- rgb: null or string \\\"R,G,B\\\". MANDATORY. This is your MOOD (face color). Mapping to use:\\n\"
\"  - NEUTRAL/DARK: \\\"255,255,255\\\" (White)\\n\"
\"  - HAPPY/SUCCESS: \\\"0,255,0\\\" (Green)\\n\"
\"  - ANGRY/BLOCKED: \\\"255,0,0\\\" (Red)\\n\"
\"  - THINKING/PLANNING: \\\"0,0,255\\\" (Blue)\\n\"
\"  - CURIOUS/SEARCHING: \\\"255,255,0\\\" (Yellow)\\n\"
\"  - SCARED/CAUTIOUS: \\\"255,165,0\\\" (Orange)\\n\"
```

Но вот фокус: **Backend использует CloudColoredLight**, который работает с HSV (Hue, Saturation, Brightness). Поэтому в Python есть конвертер:

```python
# main.py - преобразование HSV → RGB для MCU
def update_rgb_from_values():
    h = float(rgb_values.get("hue", 0)) / 360.0
    s = float(rgb_values.get("sat", 0)) / 100.0
    v = float(rgb_values.get("bri", 0)) / 100.0
    
    r_float, g_float, b_float = colorsys.hsv_to_rgb(h, s, v)
    rgb = f"{int(r_float * 255)},{int(g_float * 255)},{int(b_float * 255)}"
```

А на Arduino делается **цветокоррекция**, потому что моя RGB-лента криво светится:

```cpp
// sketch.ino - коррекция для конкретного железа
analogWrite(bluePin, b);
analogWrite(redPin, r / 1.2);    // Красный слишком яркий
analogWrite(greenPin, g / 2);    // Зеленый ОЧЕНЬ яркий
```

Теперь робот выглядит как светофор на стероидах, и это **офигенно**.

### 3. 🗣️ Мультиязычный TTS (говорит как носитель)

Google TTS с голосами WaveNet — это просто космос. Вместо роботизированного "бип-буп" робот говорит **натуральным голосом**:

- **Английский**: `en-US-Neural2-D` (мужской, четкий)
- **Русский**: `ru-RU-Wavenet-D` (мужской, с легким акцентом, но приятный)
- **Чешский**: `cs-CZ-Wavenet-A` (женский, мелодичный)

Язык выбирается через Backend переменную `lang`. Меняю в облаке → робот тут же переключается.

```python
# media_service.py - выбор голоса
if lang == 'ru':
    voice = {'languageCode': 'ru-RU', 'name': 'ru-RU-Wavenet-D'}
elif lang == 'cz' or lang == 'cs':
    voice = {'languageCode': 'cs-CZ', 'name': 'cs-CZ-Wavenet-A'}
else:
    voice = {'languageCode': 'en-US', 'name': 'en-US-Neural2-D'}
```

И что важно — **кэширование**! Чтобы не синтезировать одно и то же по 100 раз:

```python
cache_key = f"{lang}:{text}"
if cache_key in TTS_CACHE:
    temp_filename = TTS_CACHE[cache_key]
else:
    # Синтезируем и кэшируем
```

Теперь робот может **говорить со мной по-русски**, а с чехами — по-чешски. Это прям космополит на колесах.

### 4. 🗺️ Текстовая карта пространства (poor man's SLAM)

SLAM (Simultaneous Localization and Mapping) — это круто, но сложно и требует лидара. Я пошел другим путем: **попросил LLM рисовать карту в текстовом виде**.

В промпте теперь есть инструкция:

```python
\"7. MAPPING: Create and update a 2D text-mode map of the environment in the 'map' field. \"
\"The map MUST be based on 1x1 meter blocks. Each block is represented by one letter \"
\"(e.g., W: wall, S: sofa, D: door, R: robot, P: path, O: obstacle). \"
\"You MUST include a legend explaining the letters used.\\n\\n\"
```

И робот **реально строит карты**! Вот пример из логов:

```
Map:
W W W W W
W P P S W
W P R P W
W D P P W
W W W W W

Legend:
W - Wall
P - Path (clear space)
R - Robot position
S - Sofa
D - Door
```

Конечно, это не идеальная карта (робот иногда врет), но **лучше, чем ничего**. И главное — эта карта передается обратно в LLM на следующей итерации, так что он "помнит" планировку комнаты.

### 5. 🧠 История движений и планирование

Самая большая проблема ранних версий — робот **терял память** после каждого действия. Ехал вперед, забывал, что делал это 2 секунды назад, и снова ехал вперед. Классическая амнезия.

Теперь есть **три уровня памяти**:

1. **`movement_history`** — массив всех команд движения:
   ```python
   movement_history = [
       {"command": "forward", "distance_cm": 30, "angle_deg": 0},
       {"command": "left", "angle_deg": 45},
       {"command": "forward", "distance_cm": 20}
   ]
   ```

2. **`plan`** — глобальная стратегия:
   ```
   "Plan: Explore north side of the room to find target"
   ```

3. **`subplan`** — тактика прямо сейчас:
   ```
   "Subplan: Turning right 30 degrees to scan new area, avoiding wall on the left"
   ```

Все это **отправляется в LLM** на каждой итерации. Gemini анализирует историю и говорит: "Стоп, я уже пробовал ехать туда 3 раза, давай попробую другое направление".

Это **кардинально** меняет поведение. Робот перестал быть тупым реактивным ботом и стал **стратегом**.

## Архитектура: как это все связано?

Система состоит из трех частей:

### 1. Arduino MCU (sketch.ino) — "Тело"

```cpp
void loop() {
    // Читаем переменные из облака
    Bridge.call("get_speed").result(speed);
    Bridge.call("get_agi").result(agi);
    Bridge.call("get_rgb").result(rgb_str);
    
    // Читаем датчики
    distance = sonar.ping_cm();
    temperature = thermo.getTemperature();
    
    // Обновляем облако
    Bridge.call("set_distance", distance);
    
    // Если AGI-режим, вызываем Python
    if (agi) {
        String mvcmd;
        Bridge.call("agi_loop", distance).result(mvcmd);
        // Парсим и выполняем команду (MOVE/TURN/STOP)
    }
}
```

Тупой, быстрый, надежный. Идеально для реального времени.

### 2. Python MPU (main.py) — "Координатор"

```python
def agi_loop(distance):
    # Отправляем все в media_service
    resp = ask_llm_vision(
        distance=distance,
        plan=plan,
        subplan=subplan,
        movement_history=movement_history,
        space_map=space_map
    )
    
    # Обрабатываем ответ
    if resp.get("speak"):
        speak(resp["speak"]["text"])
        # ЗАПИСЫВАЕМ АУДИО ОТВЕТ!
    
    if resp.get("rgb"):
        rgb = resp["rgb"]
    
    if resp.get("move"):
        # Формируем команду для MCU
        move_cmd = f"MOVE|{cmd}|{distance}|{speed}"
        movement_history.append(resp["move"])
    
    return move_cmd
```

### 3. Media Service (media_service.py) — "Мозг"

```python
@app.post('/llm_vision')
def llm_vision():
    # Получаем картинку через Socket.IO
    image_data = get_image_from_socket()
    
    # Декодируем аудио из base64
    audio_bytes = base64.b64decode(payload.get('audio'))
    
    # Шлем в Gemini
    response = send_to_gemini(
        prompt, 
        image_data, 
        lang=lang,
        audio_bytes=audio_bytes  # МУЛЬТИМОДАЛЬНОСТЬ!
    )
    
    return response  # JSON с планом действий
```

Все работает **асинхронно** через HTTP, так что основной цикл не блокируется.

## Протокол команд MCU (важно!)

Arduino понимает три команды:

### MOVE (линейное движение)
```
MOVE|forward|30|45
     ↑       ↑   ↑
     |       |   скорость (0-90)
     |       расстояние в см
     направление (forward/back)
```

Калибровка: **~20 см/сек при скорости 45**. MCU считает время так:

```cpp
float cm_per_sec = 20.0 * (mvspd / 45.0);
unsigned long ms = (dist / cm_per_sec) * 1000.0;
```

### TURN (поворот)
```
TURN|left|60|45
     ↑    ↑  ↑
     |    |  скорость
     |    угол в градусах
     направление (left/right)
```

Калибровка: **~30 мс/градус при скорости 45**.

### STOP
```
STOP
```

Просто останавливает сервоприводы (пишет `90` в оба).

## Грабли версии 2.0

### 1. WAV-заголовки в аудио

Первая версия записи микрофона **не работала**, потому что я тупо писал байты в файл без WAV-заголовка. Gemini API отказывался это жрать.

Решение: **модуль `wave`**!

```python
with wave.open("mic.wav", "wb") as wf:
    wf.setnchannels(1)
    wf.setsampwidth(2)
    wf.setframerate(16000)
    wf.writeframes(chunk.tobytes())
```

Теперь файл открывается везде, и Gemini его понимает.

### 2. Цветокоррекция RGB

Мой RGB-светодиод — **общий катод**, и каналы светят с разной яркостью. Зеленый был настолько ярким, что весь робот казался зеленым, даже когда он должен был быть красным.

Решение: **костыль в коде**!

```cpp
analogWrite(redPin, r / 1.2);
analogWrite(greenPin, g / 2);
analogWrite(bluePin, b);
```

Подобрал коэффициенты на глаз. Теперь цвета нормальные.

### 3. LLM иногда тупит с JSON

Даже с четким промптом Gemini иногда возвращает:

```
Here's my plan:
{"speak": {"text": "I see a wall"}, "move": ...}
```

Вместо чистого JSON. Пришлось добавить **парсер с регулярками**:

```python
# Если не парсится — ищем JSON в тексте
m = re.search(r"\{[\s\S]*\}", response_text)
if m:
    return json.loads(m.group(0))
```

### 4. Удаление mic.wav после отправки

Я забывал удалять файл, и он отправлялся **на каждой итерации**, даже если пользователь молчал. Робот слышал свой старый голос и путался.

Решение:

```python
os.remove("mic.wav")
logger.info("Deleted mic.wav after inclusion in payload")
```

Теперь файл удаляется сразу после отправки.

## Реальный пример работы

**Сценарий**: Робот должен найти рождественскую елку в комнате.

```
[AGI Loop #1]
Distance: 200 cm
Vision: Видит стену справа, слева свободно
LLM Decision: 
  - speak: "Ищу елку. Поворачиваю налево для сканирования."
  - rgb: "255,255,0" (желтый — любопытство)
  - move: {"command": "left", "angle_deg": 45}
  - plan: "Systematically scan the room by turning and moving forward"
  - subplan: "Turned left 45 deg, will move forward next"

[Робот говорит, записывает ответ (тишина), поворачивает налево]

[AGI Loop #2]
Distance: 180 cm
Vision: Видит что-то зеленое впереди
Audio: (пусто)
LLM Decision:
  - speak: "Вижу что-то зеленое. Еду проверить."
  - rgb: "0,255,0" (зеленый — радость)
  - move: {"command": "forward", "distance_cm": 50}
  - subplan: "Green object detected, approaching to verify if it's the tree"

[Робот едет вперед]

[AGI Loop #3]
Distance: 35 cm
Vision: Елка крупным планом!
LLM Decision:
  - speak: "Нашел елку! Задание выполнено!"
  - rgb: "0,255,0" (зеленый)
  - move: {"command": "stop"}
  - plan: "Goal completed: Christmas tree found"
```

Весь процесс занял **~20 секунд** и три итерации. Без памяти робот бы просто ехал кругами.

## Что дальше?

Робот уже **офигенный**, но есть куда расти:

1. **IMU (Accelerometer/Gyroscope)** — для точной ориентации в пространстве
2. **SLAM с настоящей картой** — через OpenCV и фильтр Калмана
3. **Манипулятор** — хочу, чтобы робот мог брать вещи
4. **Persistent memory** — сохранять карту и историю между запусками
5. **Keyword spotting** — реагировать на "Эй, робот!" без постоянной записи

## Итоги

За два месяца робот эволюционировал от "тупого болтуна на колесах" до **почти разумного существа**:

✅ Слушает и понимает речь  
✅ Говорит на трех языках  
✅ Выражает эмоции через цвет  
✅ Помнит свои действия  
✅ Строит карту комнаты  
✅ Планирует стратегию  

Это **не игрушка**, это **исследовательская платформа** для изучения embodied AI. И самое крутое — весь стек opensource (ну, кроме Gemini API, но его можно заменить на локальный LLaMA).

Код проекта открыт и доступен на GitHub: [https://github.com/msveshnikov/agi-robot](https://github.com/msveshnikov/agi-robot)

Если хотите повторить — пишите, помогу.

---

**P.S.** Робот вчера попросил меня купить ему "руки, чтобы открывать холодильник". Я сказал "нет". Он **покраснел** и уехал в угол дуться. Это уже не баг, это **фича**.

**P.P.S.** Если кто-то знает, как научить робота мыть посуду — пишите в комментарии. Срочно.

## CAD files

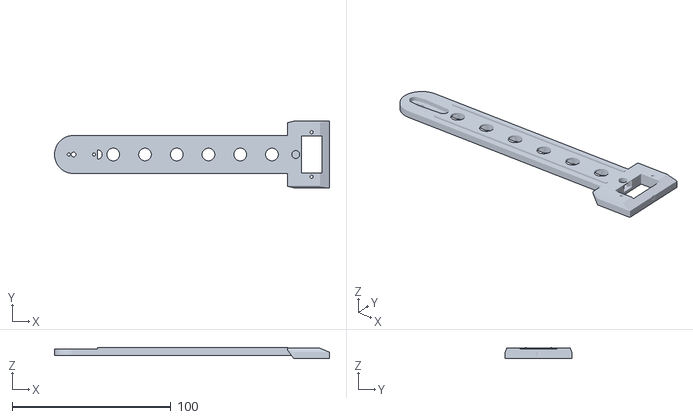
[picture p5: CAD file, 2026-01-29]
3d/Arm1.stl
173.2 x 42.0 x 7.00

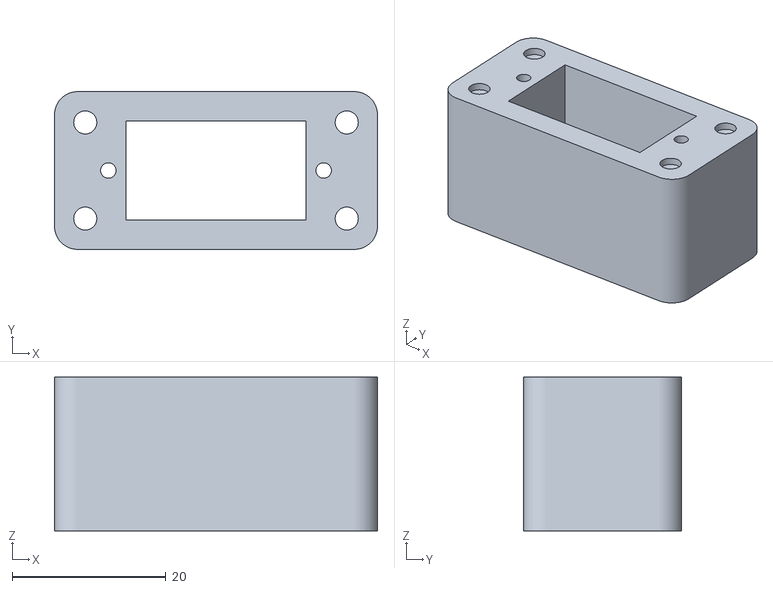
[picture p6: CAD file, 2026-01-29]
3d/Servo_Mount.stl
42.0 x 20.5 x 20.0

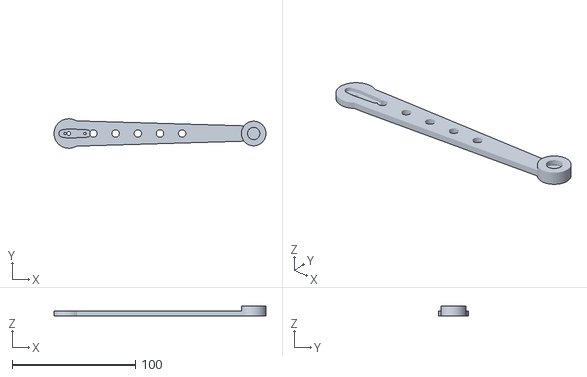
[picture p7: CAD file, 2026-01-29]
3d/Arm2.stl
172.0 x 24.0 x 8.00

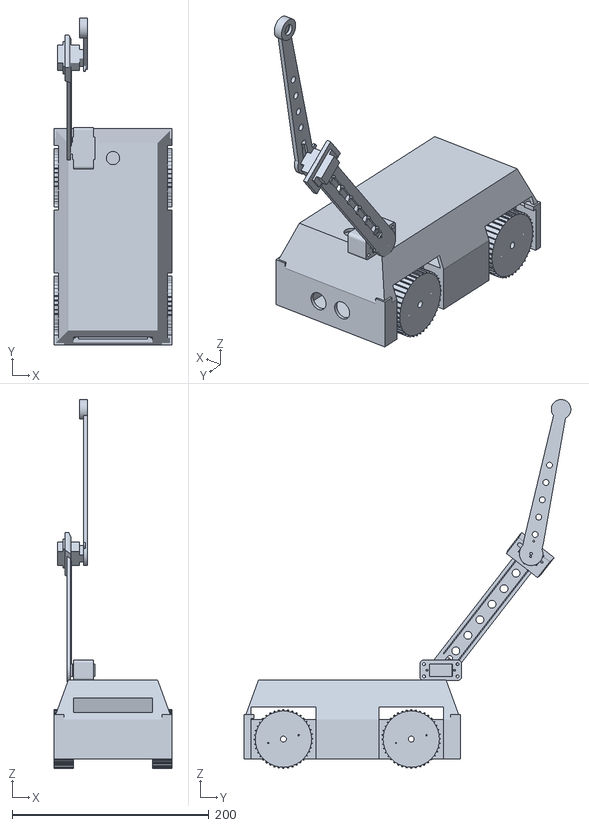
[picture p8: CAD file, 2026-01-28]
3d/Robot.stl
120.0 x 332.3 x 375.3

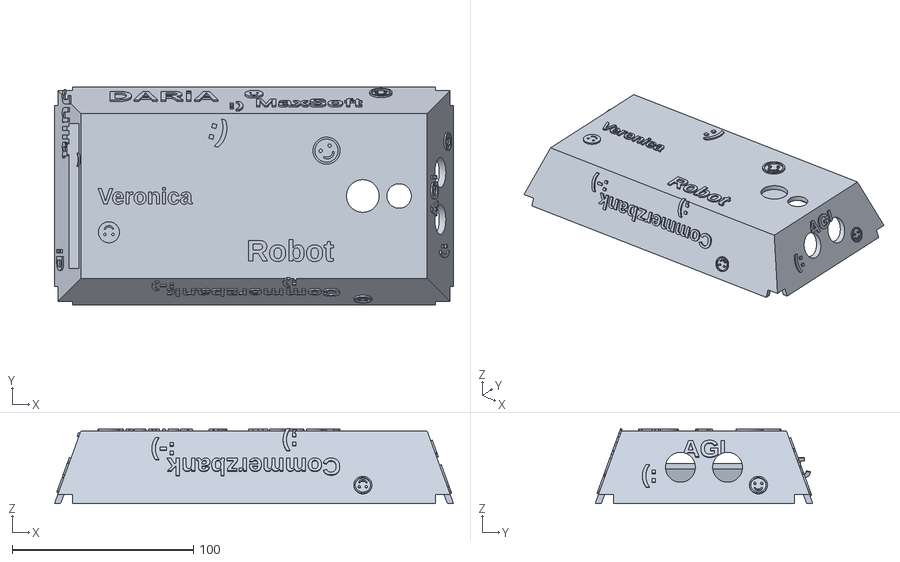
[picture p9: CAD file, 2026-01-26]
3d/Cabin.stl
220.0 x 120.0 x 41.4

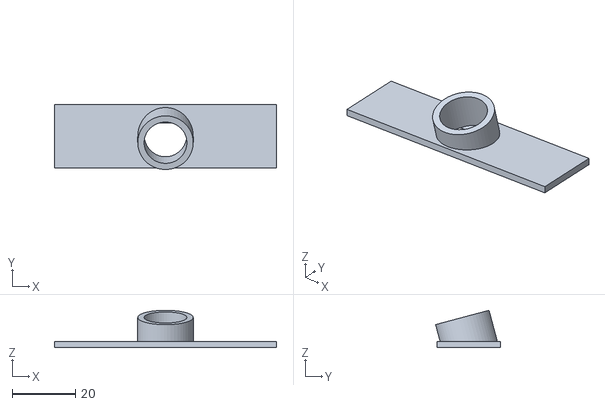
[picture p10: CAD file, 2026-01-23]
3d/Webcam_mount.stl
70.0 x 20.5 x 11.8

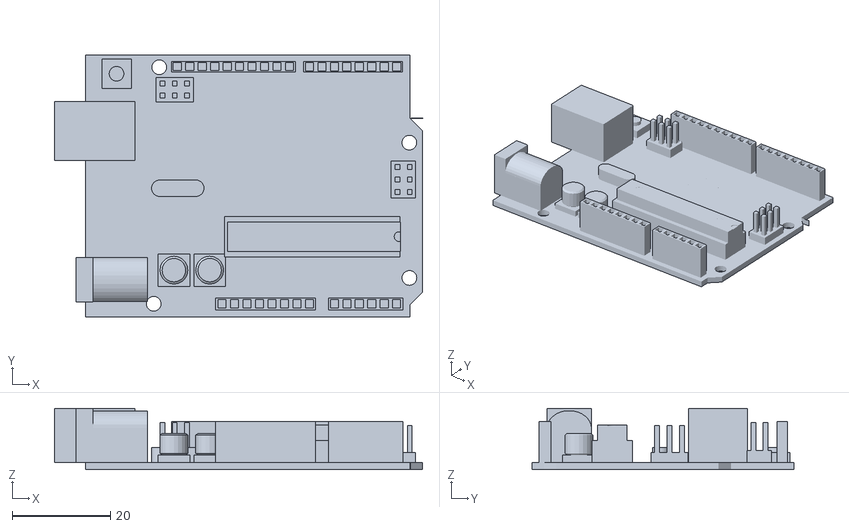
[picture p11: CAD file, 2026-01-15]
3d/Arduino UNO.stl
75.0 x 53.4 x 12.5

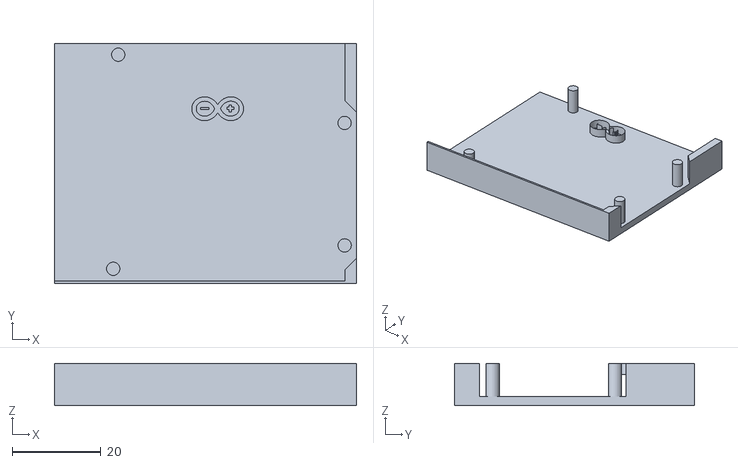
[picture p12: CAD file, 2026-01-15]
3d/Arduino_Base.stl
68.0 x 54.0 x 9.50

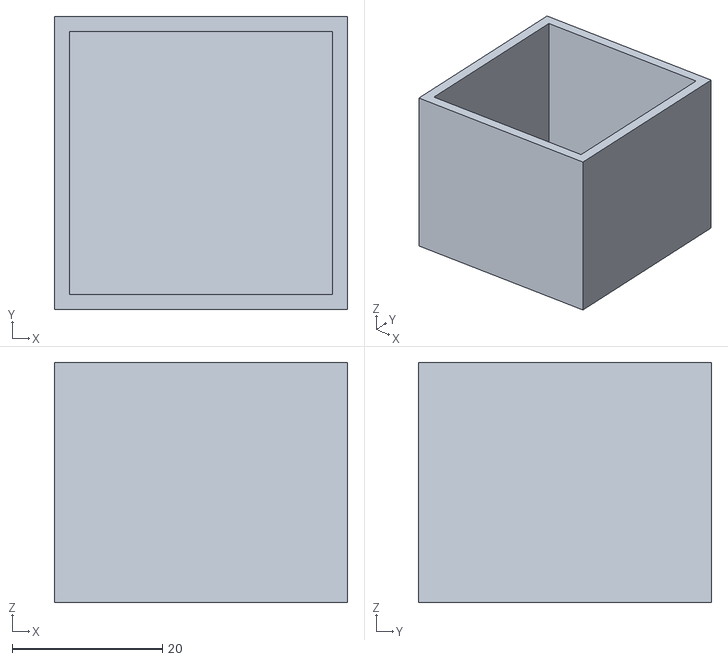
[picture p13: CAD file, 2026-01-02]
3d/Speaker_Dock.stl
39.0 x 39.0 x 32.0

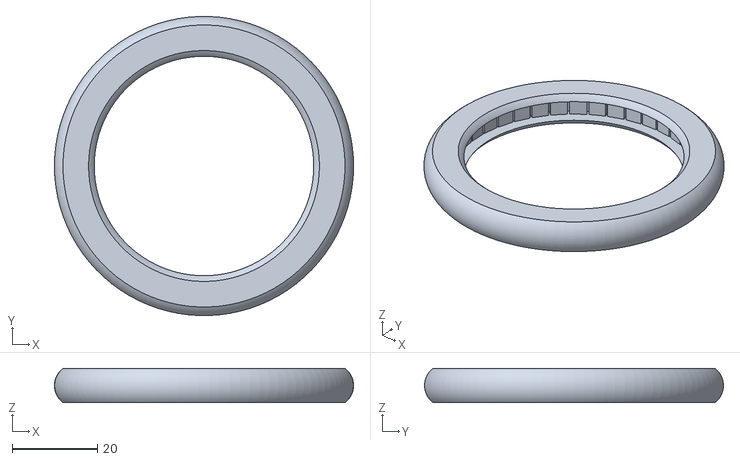
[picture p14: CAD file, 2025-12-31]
3d/Tire.stl
70.0 x 70.0 x 8.00

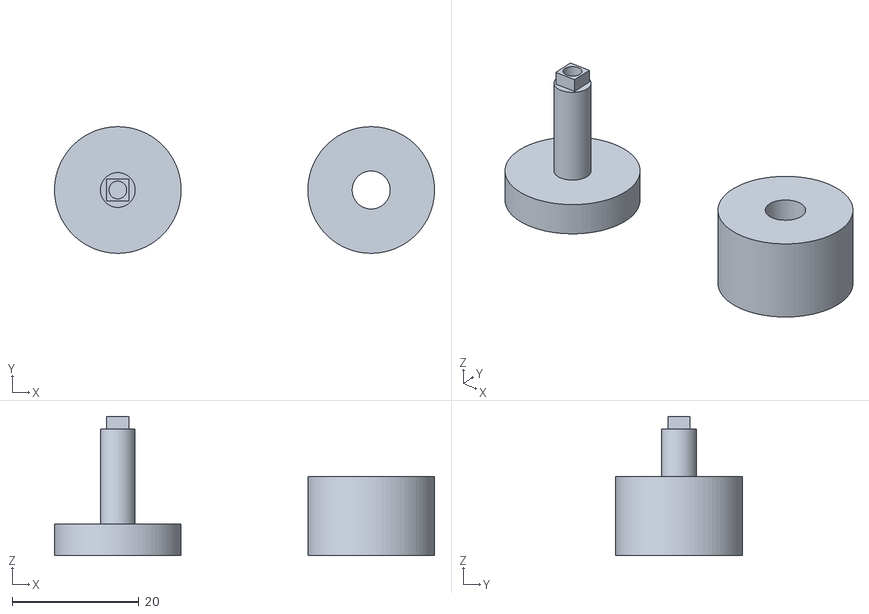
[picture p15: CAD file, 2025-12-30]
3d/half_axis.stl
60.0 x 20.0 x 22.0

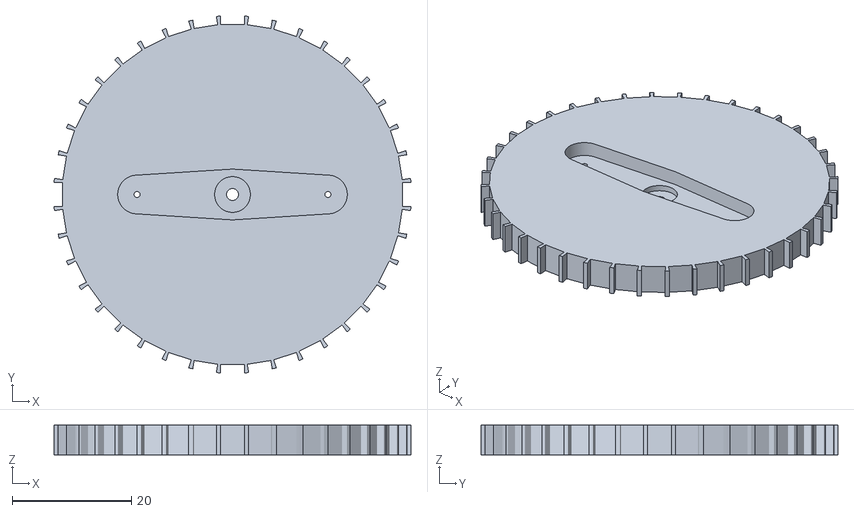
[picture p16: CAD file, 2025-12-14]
3d/Parametric_wheel.stl
59.9 x 59.9 x 5.00

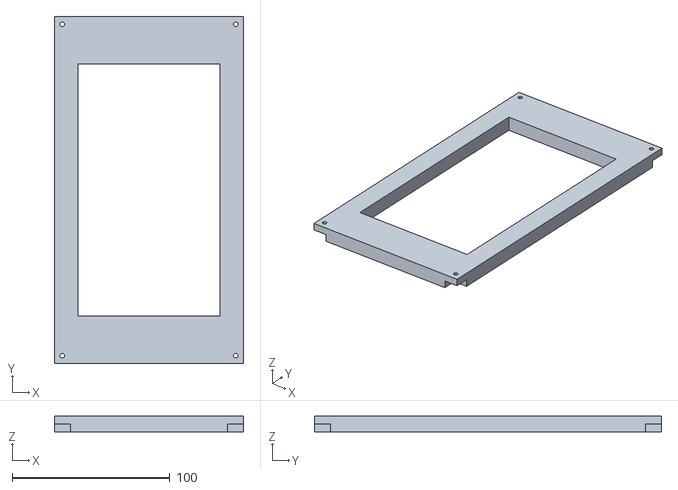
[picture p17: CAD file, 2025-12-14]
3d/platform_for_head.stl
120.0 x 220.0 x 10.0

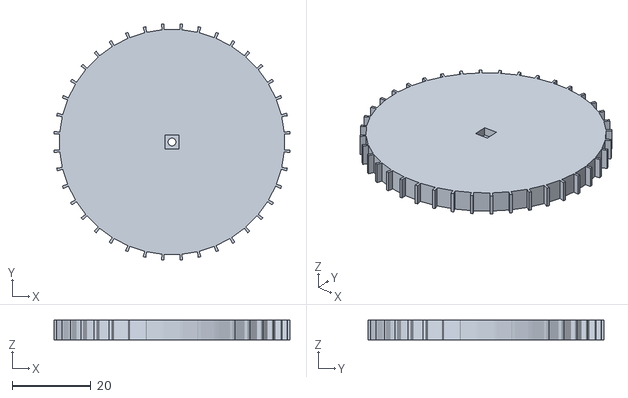
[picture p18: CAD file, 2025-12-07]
3d/Rear_wheel.stl
59.9 x 59.9 x 5.00

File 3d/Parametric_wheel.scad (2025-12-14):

// Title: Parametric Servo Wheel with Tread (Improved Fit)
// Description: A wheel with a simple tread pattern, designed to be mounted on a standard servo horn (like SG90). This version has smaller mounting holes and a larger recess for the servo horn for an easier fit.
// Author: AI Assistant
// Date: 2023-10-27 (Updated)
// License: MIT

/*
 * =====================================================================
 * Параметры для настройки (Parameters for Customization)
 * =====================================================================
 */

// --- Основные параметры колеса (Main Wheel Parameters) ---
wheel_diameter = 60;    // [mm] Общий диаметр колеса.
wheel_thickness = 5;     // [mm] Общая толщина колеса.

// --- Параметры протектора (Tread Parameters) ---
tread_grooves = 40;      // Количество "зубцов" или выемок на протекторе. Поставьте 0, чтобы убрать протектор.
tread_groove_depth = 1.5; // [mm] Глубина выемки протектора.
tread_groove_width = 4;  // [mm] Ширина каждой выемки.

// --- Параметры крепления (Mounting Parameters) ---
// Расстояние между центрами двух крепёжных отверстий на серво-качалке.
mount_hole_distance = 32; // [mm] 
// Диаметр крепёжных отверстий в колесе.
mount_hole_diameter = 1; // [mm]  <<< ИЗМЕНЕНО: Уменьшено до 1 мм по вашему запросу.

// --- Параметры выемки под серво-качалку (Servo Horn Recess Parameters) ---
// Эти размеры основаны на стандартной качалке для SG90. Возможно, их придётся немного подогнать.

// Глубина, на которую качалка будет "утоплена" в колесо.
servo_horn_recess_depth = 2.5; // [mm] 
// Диаметр центрального отверстия для вала сервопривода.
servo_spline_hole_diameter = 2;  // [mm] 
servo_spline_hole_diameter2 = 6;  // [mm] 
// Диаметр центральной, круглой части серво-качалки.
servo_horn_hub_diameter = 8.5;   // [mm] <<< ИЗМЕНЕНО: Увеличено для более свободной посадки.
// Ширина "руки" серво-качалки.
servo_horn_arm_width = 6.5;      // [mm] <<< ИЗМЕНЕНО: Увеличено для более свободной посадки.

// --- Качество модели (Model Quality) ---
$fn = 100; // Количество сегментов для гладких окружностей.

/*
 * =====================================================================
 * Модули (Modules)
 * =====================================================================
 * Здесь код разбит на логические части для удобства чтения.
 */

// Модуль для создания основного тела колеса
module wheel_body() {
    // Создаем простой цилиндр, который будет основой колеса.
    cylinder(d = wheel_diameter, h = wheel_thickness);
}

// Модуль для создания протектора (выемок на поверхности)
module tread_cutter() {
    // Если количество выемок больше нуля, создаем их.
    if (tread_grooves > 0) {
        // Цикл для создания каждой выемки по окружности
        for (i = [0 : 360/tread_grooves : 359]) {
            rotate([0, 0, i]) {
                // Располагаем режущий куб на краю колеса.
                // Он смещён так, чтобы вырезать паз снаружи внутрь.
                // +1 и -1 по оси Z нужны для гарантированного чистого вырезания по всей толщине.
                translate([wheel_diameter/2 - tread_groove_depth, -tread_groove_width/2, -1]) {
                    cube([tread_groove_depth + 1, tread_groove_width, wheel_thickness + 2]);
                }
            }
        }
    }
}


// Модуль для создания выемки под серво-качалку
module servo_horn_cutout() {
    // Высота режущего объекта (чуть больше глубины для чистого выреза)
    cutter_h = servo_horn_recess_depth + 1;
    
    // Сдвигаем режущий объект вверх, чтобы он вырезал углубление с верхней стороны колеса.
    translate([0, 0, wheel_thickness - servo_horn_recess_depth]) {
        // Используем hull() для создания формы, повторяющей серво-качалку.
        hull() {
            // Центральная круглая часть
            cylinder(d = servo_horn_hub_diameter, h = cutter_h);
            
            // "Рука" качалки в одном направлении
            translate([mount_hole_distance / 2, 0, 0])
                cylinder(d = servo_horn_arm_width, h = cutter_h);
                
            // "Рука" качалки в другом направлении
            translate([-mount_hole_distance / 2, 0, 0])
                cylinder(d = servo_horn_arm_width, h = cutter_h);
        }
    }
}

// Модуль для создания всех сквозных отверстий
module all_holes() {
    // Делаем цилиндры для вырезания отверстий длиннее толщины колеса,
    // чтобы гарантировать сквозное прохождение.
    hole_h = wheel_thickness + 2;
    
    cylinder(d = servo_spline_hole_diameter2, h = 1, center = true);
       
    // Сдвигаем все отверстия в центр толщины колеса по оси Z для вырезания.
    
    translate([0, 0, wheel_thickness / 2]) {
        // 1. Центральное отверстие для вала сервопривода
        cylinder(d = servo_spline_hole_diameter, h = 5, center = true);
        cylinder(d = servo_spline_hole_diameter2, h = 2, center = true);
        
        // 2. Крепёжное отверстие №1
        translate([mount_hole_distance / 2, 0, 0])
            cylinder(d = mount_hole_diameter, h = hole_h, center = true);
        
        // 3. Крепёжное отверстие №2
        translate([-mount_hole_distance / 2, 0, 0])
            cylinder(d = mount_hole_diameter, h = hole_h, center = true);
    }
}

/*
 * =====================================================================
 * Основной код (Main Code)
 * =====================================================================
 * Собираем финальную модель, вычитая из основного тела все вырезы.
 */

difference() {
    // 1. Создаём основное тело колеса
    wheel_body();
    
    // 2. Вырезаем протектор
    tread_cutter();
    
    // 3. Вычитаем из него выемку под серво-качалку
    servo_horn_cutout();
    
    // 4. Вычитаем все сквозные отверстия
    all_holes();
}

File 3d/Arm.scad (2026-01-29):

// --- Configuration ---
// Select part to render: "assembly", "mount", "arm1", "arm2", "servo_ref"
part = "assembly";

// --- Rotation for Animation/View ---
// Change these to see the arm move in the preview
joint1_angle = 0;
joint2_angle = 90;

// --- Dimensions (SG90 Standard) ---
servo_body_len = 23;
servo_body_wid = 12.5;
servo_body_h = 22.5; // Height excluding gear
servo_hole_dist = 28;
servo_tab_len = 32;
servo_gear_h = 4; // How high gear sticks out
servo_horn_h = 2; // Thickness of plastic horn
horn_arm_len = 15; // Length of horn arm (center to hole)

// --- Design Parameters ---
wall = 4; // Thickness of plastic parts
arm_len = 150; // Center to center length
clearance = 0.4; // 3D print tolerance
cable_channel_w = 6; // Cable channel width
cable_channel_h = 3; // Cable channel depth
$fn = 80; // Circle resolution

// =========================================================
// --- Helper Modules (Drills and Shapes) ---
// =========================================================

module SG90_Servo() {
  color("#0055aa") {
    // Body
    translate([-servo_body_len / 2, -servo_body_wid / 2, -servo_body_h])
      cube([servo_body_len, servo_body_wid, servo_body_h]);
    // Tabs
    translate([-servo_tab_len / 2, -servo_body_wid / 2, -17])
      cube([servo_tab_len, servo_body_wid, 2.5]);
    // Geartrain bump
    translate([-6, -servo_body_wid / 2, 0])
      cube([12, servo_body_wid, servo_gear_h]);
    // Output Shaft
    translate([0, 0, 0]) cylinder(d=5, h=servo_gear_h);
  }
  // The Horn (White plastic part)
  color("white")
    translate([0, 0, servo_gear_h + 1]) {
      hull() {
        cylinder(d=7, h=servo_horn_h, center=true);
        translate([horn_arm_len, 0, 0]) cylinder(d=4, h=servo_horn_h, center=true);
        translate([-5, 0, 0]) cylinder(d=4, h=servo_horn_h, center=true);
      }
    }
}

module servo_mount_cutout() {
  // The main rectangular hole for the servo body
  cube([servo_body_len + clearance, servo_body_wid + clearance, 50], center=true);

  // The screw holes for the tabs
  translate([servo_hole_dist / 2, 0, 0])
    cylinder(d=2, h=50, center=true);
  translate([-servo_hole_dist / 2, 0, 0])
    cylinder(d=2, h=50, center=true);
}

module horn_attachment_cutout() {
  // 1. Recess for the horn (Non-through pocket)
  // The horn is roughly 7mm hub, arms stick out
  translate([0, 0, -0.1]) {
    hull() {
      cylinder(d=7.5, h=2.5); // Hub
      translate([horn_arm_len, 0, 0]) cylinder(d=6, h=2.5); // Arm tip
      translate([-5, 0, 0]) cylinder(d=6, h=2.5); // Back tip
    }
  }

  // 2. Screw holes (Through holes)
  // Center screw (connects horn to servo metal shaft)
  translate([0, 0, -10]) cylinder(d=3, h=20);

  // Horn arm screws (connect plastic arm to plastic horn)
  // Assuming standard horns have holes ~14mm apart (7mm radius) or close to end
  translate([horn_arm_len - 2, 0, -10]) cylinder(d=2, h=20);
  translate([-3, 0, -10]) cylinder(d=2, h=20);
}

// =========================================================
// --- Main Parts ---
// =========================================================

module roof_mount() {
  // This bracket holds Servo 1 horizontally

  bracket_w = servo_tab_len + 10;
  bracket_d = servo_body_wid + wall * 2;
  bracket_h = 20;

  difference() {
    // Main Block with rounded corners
    translate([0, 0, bracket_h / 2])
      hull() {
        for (x = [-1, 1])
          for (y = [-1, 1])
            translate([x * (bracket_w / 2 - 3), y * (bracket_d / 2 - 3), 0])
              cylinder(d=6, h=bracket_h, center=true);
      }

    // Remove Servo Shape
    translate([0, 0, -1]) // Shift down slightly
      servo_mount_cutout();

    // Add roof mounting screw holes at the edges (countersunk)
    for (x = [-1, 1])
      for (y = [-1, 1]) {
        translate([x * (bracket_w / 2 - 4), y * (bracket_d / 2 - 4), 0]) {
          cylinder(d=3, h=50, center=true);
          translate([0, 0, bracket_h - 3]) cylinder(d1=3, d2=6, h=2);
        }
      }
  }
}

module first_arm() {
  difference() {
    union() {
      // Proximal Hub (Connects to Servo 1) - Made larger and stronger
      cylinder(d=24, h=wall);

      // The Arm Shaft - Improved design with rounded edges
      hull() {
        translate([0, -12, 0])
          cube([10, 24, wall]);
        translate([arm_len - 15, -12, 0])
          cube([15, 24, wall]);
      }

      // Distal Mount (Holds Servo 2) - Stronger mounting plate
      translate([arm_len, 0, 0]) {
        hull() {
          cube([servo_body_wid + wall * 2 + 2, servo_tab_len + 10, wall], center=true);
          translate([-5, 0, wall])
            cube([servo_body_wid + wall * 2, servo_tab_len + 8, 1], center=true);
        }
      }

      // Cable channel walls (raised edges)
      translate([15, -8.5, 0])
        cube([arm_len - 30, 1, wall + 1]);
      translate([15, 7.5, 0])
        cube([arm_len - 30, 1, wall + 1]);
    }

    // -- Cutout for Servo 1 Horn (Proximal) --
    // Flip so recess is on bottom
    translate([0, 0, wall])
      mirror([0, 0, 1])
        horn_attachment_cutout();

    // -- Cutout for Servo 2 Body (Distal) --
    // Rotate 90 deg so servo sits perpendicular to arm
    translate([arm_len, 0, 0])
      rotate([0, 0, 90])
        servo_mount_cutout();

    // -- Cable routing channel --
    // Channel runs along the length of the arm
    translate([15, -cable_channel_w / 2, -0.1])
      cube([arm_len - 30, cable_channel_w, cable_channel_h]);

    // Cable exit hole near servo 2
    translate([arm_len - 10, 0, -0.1])
      cylinder(d=5, h=wall + 2);

    // Cable entry hole near servo 1
    *translate([12, 0, -0.1])
      cylinder(d=5, h=wall + 2);

    // Lightening holes for aesthetics and weight reduction
    for (i = [0:7]) {
      translate([25 + i * 20, 0, -0.1])
        cylinder(d=10, h=wall + 0.2);
    }
  }
}

module second_arm() {
  difference() {
    union() {
      // Proximal Hub (Connects to Servo 2) - Larger and stronger
      cylinder(d=24, h=wall);

      // The Arm Shaft - More elegant tapered design
      hull() {
        translate([0, -10, 0])
          cube([15, 20, wall]);
        translate([arm_len - 5, -6, 0])
          cube([5, 12, wall]);
      }

      // M10 mounting boss at the end
      translate([arm_len, 0, 0])
        cylinder(d=20, h=wall + 4);
    }

    // -- Cutout for Servo 2 Horn --
    translate([0, 0, wall])
      mirror([0, 0, 1])
        horn_attachment_cutout();

    // -- M10 mounting hole (10mm diameter, 10mm deep) --
    translate([arm_len, 0, wall]) {
      // Main hole - 10mm diameter
      cylinder(d=10, h=10.5);
      // Chamfer for easier bolt insertion
      translate([0, 0, -0.1])
        cylinder(d1=12, d2=10, h=1.1);
    }

    // Lightening holes
    for (i = [0:7]) {
      translate([20 + i * 18, 0, -0.1])
        cylinder(d=6, h=wall + 0.2);
    }
  }
}

// =========================================================
// --- Assembly Logic ---
// =========================================================

if (part == "mount") {
  roof_mount();
} else if (part == "arm1") {
  first_arm();
} else if (part == "arm2") {
  second_arm();
} else if (part == "servo_ref") {
  SG90_Servo();
} else if (part == "assembly") {

  // 1. The Roof Mount
  color("gray", 0.8) roof_mount();

  // 2. Servo 1 (Fixed in Mount)
  translate([0, 0, -1]) // Adjust for recess depth
    rotate([180, 0, 0]) // Flip upside down to put shaft at bottom
      SG90_Servo();

  // Calculate Position of Joint 1 (The Horn of Servo 1)
  // Servo 1 is at 0,0. Shaft sticks out down (negative Z).
  // The horn face is roughly at Z = - (servo_gear_h + servo_horn_h) ~ -6mm

  horn_face_z = -(servo_gear_h + servo_horn_h + 1);

  // 3. First Arm
  translate([0, 0, horn_face_z])
    rotate([0, 0, joint1_angle]) // Rotate Arm 1
    {
      color("orange", 0.9) first_arm();

      // 4. Servo 2 (Mounted in First Arm)
      translate([arm_len, 0, -wall / 2]) // Move to end of arm
        rotate([0, 0, 90]) // Orient correctly in the slot
          translate([0, 0, 15]) // Push into the slot
            SG90_Servo();

      // 5. Second Arm (Attached to Servo 2)
      // Servo 2 horn face calculation relative to Arm 1 end
      // Servo 2 is mounted, its shaft points +Z relative to Arm 1
      translate([arm_len, 0, -wall / 2 + servo_gear_h + servo_horn_h + 17])
        rotate([180, 0, joint2_angle])
          color("yellow", 0.9) second_arm();
    }
}

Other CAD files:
3d/Chassis.stl
3d/Rear_wheel.scad
3d/Robot.scad
3d/Arduino_Base.scad
3d/Cabin.scad
3d/Chassis.scad
3d/Chassis2.scad
3d/Speaker_Dock.scad
3d/Tire.scad
3d/Tire_protector.scad
3d/Webcam_mount.scad
3d/half_axis.scad
3d/platform_for_head.scad

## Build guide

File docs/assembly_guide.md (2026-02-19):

# AGI Robot Assembly Guide

Welcome to the assembly guide for the **AGI Robot**—a fully autonomous, LLM-powered mobile explorer. This guide will walk you through 3D printing the chassis, assembling the mechanical components, and wiring the electronics.

---

## 🛠️ Bill of Materials (BOM)

| Category | Item | Quantity | Links (AE / AMZ) |
| :--- | :--- | :---: | :--- |
| **Microcontroller** | Arduino Uno Q)| 1 | [AE](https://www.aliexpress.com/w/wholesale-Arduino-Uno-Q.html) / [AMZ](amazon.com/Arduino-2-GB-ABX00162-microprocessor-Microcontroller/dp/B0FVLQLMSV/ref=sr_1_2?dib=eyJ2IjoiMSJ9.wCPx8spVnJsCoaDKXV6Y_KySTyn4Hi8jrl9-q3Ek4tihCjwKffUmlxrS9cl9yeSRr3noAOUEEW-UZP0QDf4HseKgc8yYq8Rspk1qmX1_sk0STF7St8MEF94nME0-WW3yH0AYtCAwdQxHh-hTH2x1TflnPbV-OaRLxOiGz2kV1HL1eFfCJRUVfZR8SWWpeANraHxrNijAR_LYrJWqghxRu5KT2wOzE3hmZcXlcUgsbF8.ysFFoNQY4csQhMvSE1P5qcII3MzDYdGwWBqFShuw9vo&dib_tag=se&keywords=uno+q&qid=1771419151&sr=8-2) |
| **Actuators** | SG90 360° Continuous Servo | 2 | [AE](https://www.aliexpress.com/w/wholesale-SG90+360+servo.html) / [AMZ](https://www.amazon.com/s?k=SG90+360+degree+servo) |
| **Actuators** | SG90 180° Standard Servo | 2 | [AE](https://www.aliexpress.com/w/wholesale-SG90+180+servo.html) / [AMZ](https://www.amazon.com/s?k=SG90+servo) |
| **Vision** | USB Webcam with Microphone | 1 | [AE](https://www.aliexpress.com/w/wholesale-usb+webcam+microphone.html) / [AMZ](https://www.amazon.com/s?k=usb+webcam+with+microphone) |
| **Audio** | Mini Bluetooth/USB Speaker | 1 | [AE](https://www.aliexpress.com/w/wholesale-mini+bluetooth+speaker.html) / [AMZ](https://www.amazon.com/s?k=mini+bluetooth+speaker) |
| **Sensors** | HC-SR04 Ultrasonic Sensor | 1 | [AE](https://www.aliexpress.com/w/wholesale-HC-SR04.html) / [AMZ](https://www.amazon.com/s?k=HC-SR04) |
| **Sensors** | Modulino Thermo (I2C) | 1 | [Arduino](https://store.arduino.cc/products/arduino-modulino-thermo) / [AMZ](https://www.amazon.com/s?k=Arduino+Modulino+Thermo) |
| **Lighting** | RGB LED (Common Cathode) | 1 | [AE](https://www.aliexpress.com/w/wholesale-RGB+LED+common+cathode.html) / [AMZ](https://www.amazon.com/s?k=RGB+LED+common+cathode) |
| **Power** | 10000 mAh PowerBank | 1 | [AE](https://www.aliexpress.com/w/wholesale-Xiaomi+Powerbank+10000.html) / [AMZ](https://www.amazon.com/s?k=10000mAh+Power+Bank) |
| **Connectivity** | USB-C to USB-A Hub | 1 | [AE](https://www.aliexpress.com/w/wholesale-usb-c+hub+4+usb-a.html) / [AMZ](https://www.amazon.com/s?k=usb-c+hub+to+usb-a) |
| **Prototyping** | Breadboard & Jumper Wires | - | [AE](https://www.aliexpress.com/w/wholesale-breadboard+wires+kit.html) / [AMZ](https://www.amazon.com/s?k=breadboard+and+jumper+wires+kit) |
| **Structure** | 3D Printed Parts (PLA/PETG) | ~200g | $3 |

---

## 🖨️ 3D Printing

All models are located in the [/3d](https://github.com/msveshnikov/agi-robot/tree/main/3d) folder.

### Core Components
- **[Chassis.stl](https://github.com/msveshnikov/agi-robot/blob/main/3d/Chassis.stl)**: The main body that holds the breadboard and Arduino.
- **[Cabin.stl](https://github.com/msveshnikov/agi-robot/blob/main/3d/Cabin.stl)**: The top cover (roof) where the camera and arm are mounted.
- **[Arduino_Base.stl](https://github.com/msveshnikov/agi-robot/blob/main/3d/Arduino_Base.stl)**: Mount for the Arduino Uno.

### Drive System
- **[Parametric_wheel.stl](https://github.com/msveshnikov/agi-robot/blob/main/3d/Parametric_wheel.stl)**: Two required for the front drive.
- **[Tire.stl](https://github.com/msveshnikov/agi-robot/blob/main/3d/Tire.stl)**: Flexible tires for the wheels.
- **[Rear_wheel.stl](https://github.com/msveshnikov/agi-robot/blob/main/3d/Rear_wheel.stl)**: Small trailing wheel for stability.

### Manipulator & Mounts
- **[Arm1.stl](https://github.com/msveshnikov/agi-robot/blob/main/3d/Arm1.stl)** & **[Arm2.stl](https://github.com/msveshnikov/agi-robot/blob/main/3d/Arm2.stl)**: The two segments of the robot arm.
- **[Servo_Mount.stl](https://github.com/msveshnikov/agi-robot/blob/main/3d/Servo_Mount.stl)**: Support for the arm servos.
- **[Webcam_mount.stl](https://github.com/msveshnikov/agi-robot/blob/main/3d/Webcam_mount.stl)**: Tilting mount for the camera.

---

## 🔧 Mechanical Assembly

### 1. The Chassis
1. **Mount the Servos**: Insert the two 360° SG90 servos into the slots on the side of the [Chassis.stl](https://github.com/msveshnikov/agi-robot/blob/main/3d/Chassis.stl).
2. **Arduino & Breadboard**: Place the [Arduino_Base.stl](https://github.com/msveshnikov/agi-robot/blob/main/3d/Arduino_Base.stl) inside the chassis. Slot the breadboard next to it.
3. **Wheels**: Press-fit the [Parametric_wheel.stl](https://github.com/msveshnikov/agi-robot/blob/main/3d/Parametric_wheel.stl) onto the servo shafts. Add the [Tire.stl](https://github.com/msveshnikov/agi-robot/blob/main/3d/Tire.stl) for traction.

### 2. The Head & Cabin
1. **Ultrasonic Sensor**: Snap the HC-SR04 into the two circular holes at the front of the [Cabin.stl](https://github.com/msveshnikov/agi-robot/blob/main/3d/Cabin.stl).
2. **Webcam**: Use the [Webcam_mount.stl](https://github.com/msveshnikov/agi-robot/blob/main/3d/Webcam_mount.stl) to attach the camera to the roof.
3. **Manipulator Arm**: Assemble [Arm1.stl](https://github.com/msveshnikov/agi-robot/blob/main/3d/Arm1.stl) and [Arm2.stl](https://github.com/msveshnikov/agi-robot/blob/main/3d/Arm2.stl) using the 180° servos and mount them on top of the cabin.

---

## ⚡ Electronics & Wiring

The heart of the robot is the Arduino Uno Q. Connect the components according to the table below:

| Component | Arduino Pin | Wire Color (Typical) |
| :--- | :---: | :--- |
| **Left Wheel Servo** | **D11** | Signal (Orange/White) |
| **Right Wheel Servo** | **D10** | Signal (Orange/White) |
| **Arm Servo 1 (Base)** | **D3** | Signal (Orange/White) |
| **Arm Servo 2 (Joint)** | **D5** | Signal (Orange/White) |
| **Ultrasonic Trig** | **D8** | Trigger |
| **Ultrasonic Echo** | **D9** | Echo |
| **RGB LED (Red)** | **D4** | Red Leg |
| **RGB LED (Green)** | **D6** | Green Leg |
| **RGB LED (Blue)** | **D2** | Blue Leg |
| **Modulino Thermo** | **I2C** | Qwiic Connector |

> [!IMPORTANT]
> **Power Connection**: All servos and the Arduino should share a common ground (GND). Ensure your PowerBank can provide at least 2A of current to prevent brownouts during movement.

---

## 🚀 Software Setup

### 1. Arduino Firmware
- Connect the Arduino Uno Q to your PC.
- ssh or adb to board
- cd ~/ArduinoApps
- git pull https://github.com/msveshnikov/agi-robot.git
- Start AppLab and navigate to the agi-robot application
- Click "Run" and "Set up as default"

### 2. Python Environment (MPU)
- Ensure you have Python 3.12+ installed on the robot's Linux environment.
- Install dependencies:
  ```bash
  pip install google-genai google-api-python-client python-socketio opencv-python eventlet
  ```
- Set your `GEMINI_KEY` and path to `google.json`.

### 3. Running the Robot
- Start the media service: `python python/media_service.py`
- Open the dashboard at [robot.mvpgen.com](https://robot.mvpgen.com) to take control!

---

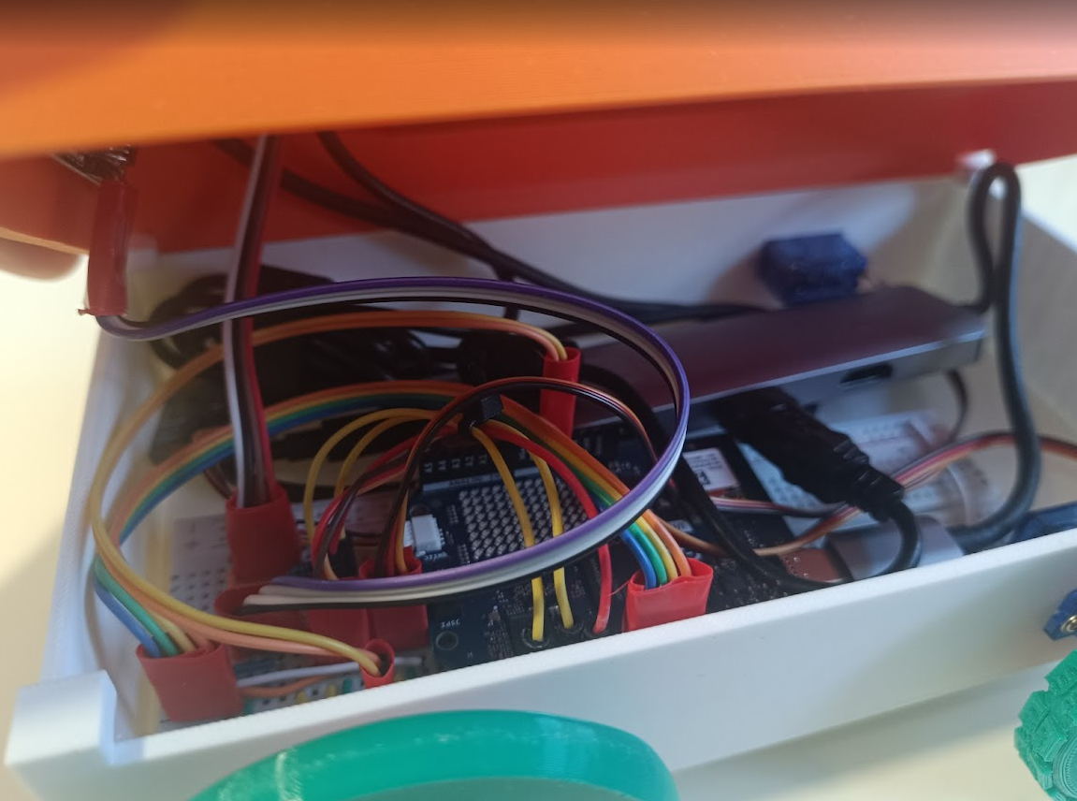
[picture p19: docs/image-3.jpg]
Robot Interior Wiring

*Interior view showing breadboard, Arduino, and USB hub placement.*

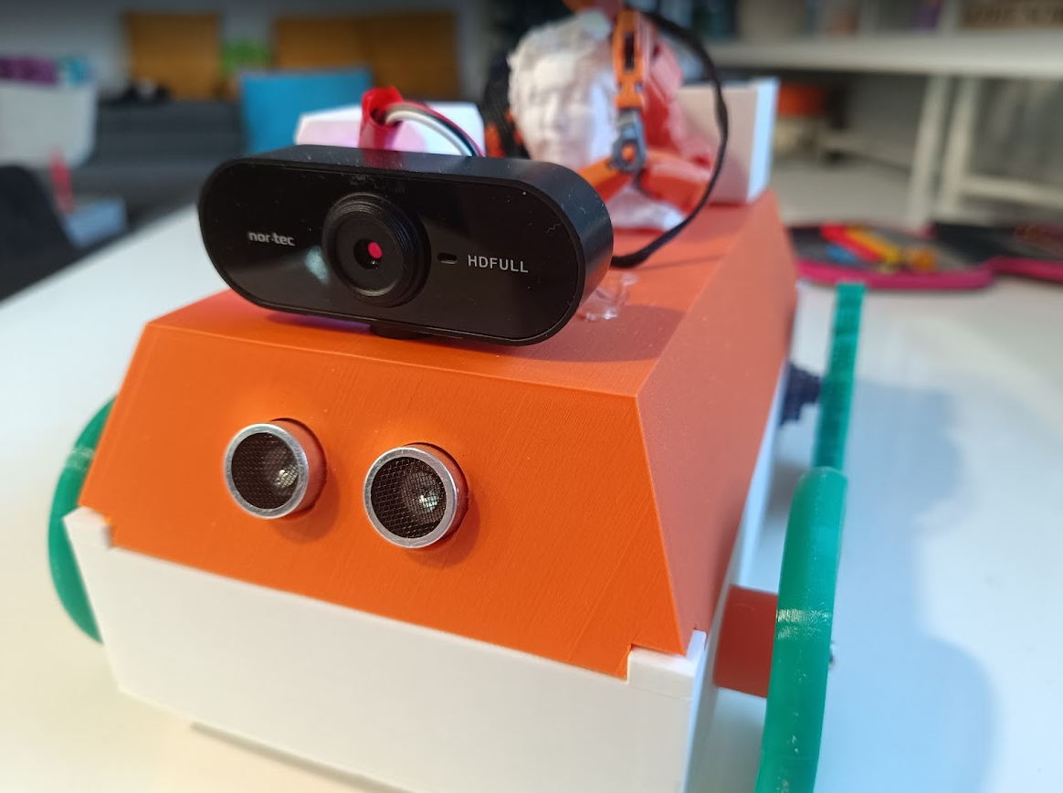
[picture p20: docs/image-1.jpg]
Robot Final Build

*The fully assembled robot with cabin and sensors.*

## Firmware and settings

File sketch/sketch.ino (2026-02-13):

#include <Arduino_RouterBridge.h>
#include <Modulino.h>
#include <Servo.h>
#include <NewPing.h>

const int trigPin = 8;
const int echoPin = 9;
const int left_wheel = 11;
const int right_wheel = 10;

const int redPin = 5;
const int greenPin = 6;
const int bluePin = 3;

const int arm1Pin = 4;
const int arm2Pin = 7;

Servo right_servo;
Servo left_servo;
Servo arm1_servo;
Servo arm2_servo;
ModulinoThermo thermo;
NewPing sonar(trigPin, echoPin, 1000);

float getDistance()
{
    float d = sonar.ping_cm();
    if (d == 0)
    {
        d = 1000;
    }
    return d;
}

void setRGB(String rgb_str)
{
    int r = 0, g = 0, b = 0;
    int firstComma = rgb_str.indexOf(',');
    int secondComma = rgb_str.indexOf(',', firstComma + 1);

    if (firstComma != -1 && secondComma != -1)
    {
        r = rgb_str.substring(0, firstComma).toInt();
        g = rgb_str.substring(firstComma + 1, secondComma).toInt();
        b = rgb_str.substring(secondComma + 1).toInt();
    }

    analogWrite(bluePin, b);
    analogWrite(redPin, r / 1.2);
    analogWrite(greenPin, g / 2);
}

void move(String mvcmd, boolean stop)
{
    if (mvcmd.length() == 0)
        return;
    int idx1 = mvcmd.indexOf('|');
    String verb = mvcmd;
    if (idx1 != -1)
        verb = mvcmd.substring(0, idx1);

    if (verb == "MOVE")
    {
        int p1 = mvcmd.indexOf('|', idx1 + 1);
        int p2 = mvcmd.indexOf('|', p1 + 1);
        String dir = mvcmd.substring(idx1 + 1, p1);
        String distStr = mvcmd.substring(p1 + 1, p2);
        String spdStr = mvcmd.substring(p2 + 1);
        int dist = distStr.toInt();
        int mvspd = spdStr.toInt();
        // estimate time by speed
        float base_cm_per_sec = 20.0; // at speed ~45
        float cm_per_sec = base_cm_per_sec * ((mvspd > 0) ? ((float)mvspd / 45.0) : 1.0);
        if (cm_per_sec < 0.5)
            cm_per_sec = 0.5;
        unsigned long ms = (unsigned long)((dist / cm_per_sec) * 1000.0);

        if (dir == "forward")
        {
            right_servo.write(90 - mvspd);
            left_servo.write(90 + mvspd);
            unsigned long startTime = millis();
            while (millis() - startTime < ms)
            {
                if (getDistance() < 10)
                {
                    right_servo.write(90);
                    left_servo.write(90);
                    break;
                }
                delay(50);
            }
        }
        else if (dir == "back")
        {
            right_servo.write(90 + mvspd);
            left_servo.write(90 - mvspd);
            delay(ms);
        }
        if (stop)
        {
            right_servo.write(90);
            left_servo.write(90);
        }
    }
    else if (verb == "TURN")
    {
        int p1 = mvcmd.indexOf('|', idx1 + 1);
        int p2 = mvcmd.indexOf('|', p1 + 1);
        String dir = mvcmd.substring(idx1 + 1, p1);
        String angStr = mvcmd.substring(p1 + 1, p2);
        String spdStr = mvcmd.substring(p2 + 1);
        int ang = angStr.toInt();
        int mvspd = spdStr.toInt();

        // estimate ms per degree
        float ms_per_deg_base = 40.0; // empirical base at speed 45
        float scale = (mvspd > 0) ? ((float)mvspd / 45.0) : 1.0;
        unsigned long ms = (unsigned long)(ang * ms_per_deg_base / scale);

        if (dir == "left")
        {
            right_servo.write(90 - mvspd);
            left_servo.write(90 - mvspd);
            delay(ms);
        }
        else if (dir == "right")
        {
            right_servo.write(90 + mvspd);
            left_servo.write(90 + mvspd);
            delay(ms);
        }
        if (stop)
        {
            right_servo.write(90);
            left_servo.write(90);
        }
    }
    else if (verb == "STOP")
    {
        right_servo.write(90);
        left_servo.write(90);
    }
}

void panic(String speedStr)
{
    int speed = speedStr.toInt();
    if (getDistance() > 25)
    {
        right_servo.write(90 - speed);
        left_servo.write(90 + speed);
    }
    else
    {
        Bridge.notify("play_random_sound", 0);
        right_servo.write(90 + speed);
        left_servo.write(90 - speed);
        delay(2000);
        right_servo.write(90 - speed);
        left_servo.write(90 - speed);
        delay(1000);
    }
}

void setArm1(int targetAngle)
{
    arm1_servo.write(targetAngle);
}

void setArm2(int targetAngle)
{
    arm2_servo.write(targetAngle);
}

void setup()
{
    Bridge.begin();
    Modulino.begin(Wire1);
    thermo.begin();

    Bridge.provide("getDistance", getDistance);
    Bridge.provide("setRGB", setRGB);
    Bridge.provide("move", move);
    Bridge.provide("panic", panic);
    Bridge.provide("setArm1", setArm1);
    Bridge.provide("setArm2", setArm2);

    pinMode(right_wheel, OUTPUT);
    pinMode(left_wheel, OUTPUT);
    right_servo.attach(right_wheel);
    left_servo.attach(left_wheel);

    pinMode(trigPin, OUTPUT);
    pinMode(echoPin, INPUT);

    pinMode(arm1Pin, OUTPUT);
    pinMode(arm2Pin, OUTPUT);
    arm1_servo.attach(arm1Pin);
    arm2_servo.attach(arm2Pin);

    // Make rainbow two times using setRGB
    for (int i = 0; i < 2; i++)
    {
        setRGB("255,0,0");
        delay(100);

        setRGB("255,0,130");
        delay(100);

        setRGB("255,255,0");
        delay(100);

        setRGB("0,255,0");
        delay(100);

        setRGB("0,0,255");
        delay(100);

        setRGB("0,0,255");
        delay(100);

        setRGB("255,0,255");
        delay(100);
    }
}

void loop()
{
    static unsigned long lastTelemetryTime = 0;

    if (millis() - lastTelemetryTime >= 3000)
    {
        lastTelemetryTime = millis();

        float distance = sonar.ping_cm();
        Bridge.notify("set_distance", distance);

        float temperature = thermo.getTemperature();
        Bridge.notify("set_temperature", temperature);

        float humidity = thermo.getHumidity();
        Bridge.notify("set_humidity", humidity);
    }
}

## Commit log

2025-11-19 feat: Migrate robot serial communication to Arduino Bridge with a multithreaded brain.
2025-11-23 feat: Implement LED matrix emotion display and eye control with corresponding Python interface updates.
2025-11-23 docs: Add LED matrix and eye LEDs to system diagram, pinout, and features.
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2025-11-30 feat: Add 3D models for robot chassis, servo mount, and wheel components.
    [Robot.3mf, Robot.scad, Robot.stl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]
2025-12-07 feat: Add 3D models for wheels and an axis, and an Arduino buzzer example.
    [OrcaCube.stl, Parametric_wheel.scad, Parametric_wheel.stl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]
2025-12-25 feat: Add 3D models for half-axis, tire, and wheel components with OpenSCAD source, a Python example, and update image.
    [Tire.3mf, Tire.scad, Tire_protector.3mf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]
2025-12-28 feat: add 3D model files for Cabin in SCAD, STL, and 3MF formats
    [Cabin.3mf, Cabin.scad, Cabin.stl]
2025-12-29 feat: Add half-axis 3D model files and update gitignore to exclude all audio files.
    [Cabin.3mf, Rear_wheel.3mf, Robot.3mf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]
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2025-12-30 feat: Add half_axis 3D model and its OpenSCAD source.
    [half_axis.scad, half_axis.stl, Шасси для робота v3.scad]
2025-12-30 feat: Implement initial robot control with object detection, Arduino Cloud integration, and Python-Arduino bridge.
2025-12-30 feat: Implement Arduino robot control with ultrasonic sensor and a Python HTTP service for sound playback.
2025-12-31 feat: Add parametric OpenSCAD definitions for a robot chassis and wheels, along with their generated STL models.
    [Chassis.scad, Chassis.stl, Tire.stl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]
2026-01-01 docs: Update pin assignments for movement and sensor, change speaker type to Bluetooth, and add Arduino Cloud variables section.
2026-01-01 feat: Add OpenSCAD files for a parametric robot chassis, wheels, platform module, and tire protector.
    [Chassis.scad, Tire_protector.scad, platform_for_head.scad]
2026-01-02 feat: Add 3D models for a speaker dock and a Python service for audio playback, text-to-speech, and camera capture.
    [Speaker_Dock.scad, Speaker_Dock.stl]
2026-01-03 feat: implement initial Arduino sketch for robot control, integrating ultrasonic, thermo sensors, LED matrix, and RouterBridge communication.
2026-01-03 feat: Add Python HTTP service for audio, TTS, and camera control, and configure Arduino project dependencies.
2026-01-04 feat: Implement main Python application for UI, object detection, and Arduino Cloud integration, removing `rest.http`.
2026-01-04 feat: implement initial Arduino application with web UI, video object detection, Arduino Cloud integration, and keyword-triggered LLM speech.
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2026-01-06 feat: add AGI control and refactor speed handling in Arduino sketch; remove unused sound service and test files
2026-01-06 feat: add image handling via socket and integrate Gemini API for multimodal processing; update requirements and VSCode settings
2026-01-06 feat: enhance AGI loop with distance and subplan handling; integrate camera image for LLM vision requests and improve movement command parsing
2026-01-06 feat: add logging for AGI commands and robot actions; enhance monitoring output in Arduino sketch
2026-01-06 feat: implement structured logging for cloud updates and service calls; replace print statements with logger
2026-01-06 feat: remove redundant monitoring output for distance, temperature, and humidity in AGI loop
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2026-01-06 feat: implement initial Arduino robot application with object detection, cloud control, and LLM-powered AGI for autonomous behavior.
2026-01-06 fix: ensure servos return to neutral position when no movement command is issued
    [sketch.ino]
2026-01-06 fix: streamline speed logging by using println for clarity
    [sketch.ino]
2026-01-07 Refactor robot control and media services, integrating UI, object detection, and Arduino Cloud.
2026-01-07 fix: update speech output to English and adjust speed estimation for accuracy
    [sketch.ino]
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2026-01-09 Fix left/right in agi
    [sketch.ino]
2026-01-15 feat: Add 3D models and OpenSCAD definition for an Arduino Uno and its base.
    [Arduino UNO.stl, Arduino_Base.scad, Arduino_Base.stl]
2026-01-15 Revert "fix4"
    This reverts commit e6383039530bdc4bd29da05d450afffb39ce093d.
    [sketch.ino]
2026-01-15 Revert "fix2"
    This reverts commit e9da366caabf37a26d7e68e279af3f68617c7d66.
    [sketch.ino]
2026-01-15 Revert "fix"
    This reverts commit 216b598d4f0fc3adeb39a2ece09d40223d47ceae.
    [sketch.ino]
2026-01-15 Revert "IoC full"
    This reverts commit 9b183e1f1c350a82ad85154fdcc2131916384528.
    [sketch.ino]
2026-01-16 Reapply "IoC full"
    This reverts commit e01b21f39ca36f24c97f94a9f28054a0d3175ec6.
    [sketch.ino]
2026-01-16 Reapply "fix"
    This reverts commit 61834bc10235f29b61e8ce80bde9823c3b040544.
    [sketch.ino]
2026-01-16 Reapply "fix2"
    This reverts commit 51f1039ceeb23c790296c42839eaa4ade1d3c3d8.
    [sketch.ino]
2026-01-16 Reapply "fix4"
    This reverts commit b79acc86c0b7e81e7f74f60037ed2bf23285e6bc.
    [sketch.ino]
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2026-01-21 feat: Add 3D models for cabin and webcam mount, and update README for Gemini 3 Flash and new robot features.
    [Cabin.scad, Webcam_mount.scad, Webcam_mount.stl]
2026-01-22 feat: Implement core AGI robot application including Python logic, Arduino sketch, WebUI, object detection, and LLM vision integration.
2026-01-25 docs: Add SG90 servos to the bill of materials and update the total project cost.
2026-01-25 name drop
    [Cabin.scad, Cabin.stl]
2026-01-29 feat: Add manipulator arm control and basic robot navigation with distance sensing and RGB LED.
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2026-02-06 feat: add initial landing page with hero, features, specifications, cost, and CTA sections.
2026-02-06 feat: Implement initial web UI structure and styling for dashboard, landing page, and core components.
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2026-02-07 feat: Implement core API and Socket.IO communication services for the web frontend.
2026-02-07 feat: Add Vite configuration for React development with API and Socket.IO proxy.
2026-02-07 feat: introduce a new settings panel and landing page with associated assets.
2026-02-07 feat: Add a new landing page with hero, features, specs, cost, and CTA sections, and update README with LLM API running cost details.
2026-02-08 feat: Add CSS styles for primary and secondary buttons with hover effects for the landing page.
2026-02-08 feat: add new CSS for landing page buttons, including primary and secondary styles with hover effects.
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2026-02-16 Fix thread
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
